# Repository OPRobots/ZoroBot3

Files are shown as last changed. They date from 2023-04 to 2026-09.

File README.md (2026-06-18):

# ZoroBot3

Tercera versión de nuestro primer robot. Un robot micromouse de alto rendimiento con STM32F4, encoders magneticos de alta resolución, succión y muchos leds molones.

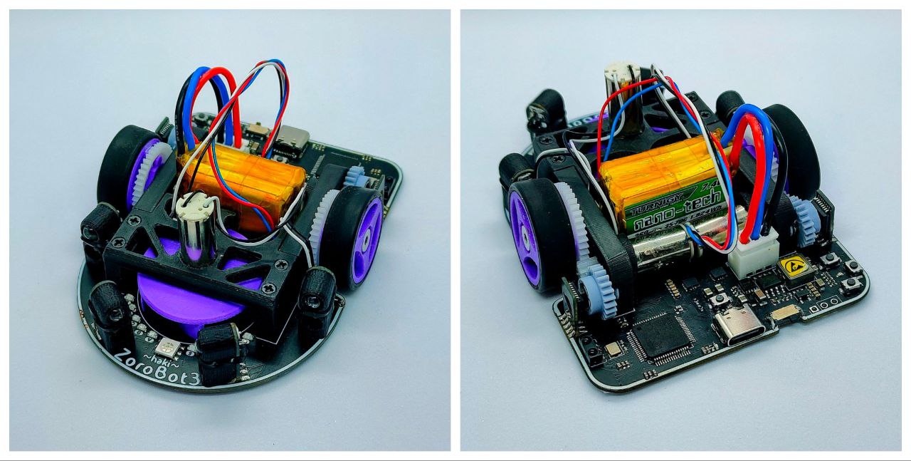
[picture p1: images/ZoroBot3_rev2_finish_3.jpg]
ZoroBot3


## 🏆 Palmarés

| 🥇 | 🥈 | 🥉 |
|:--:|:--:|:--:|
| **8** | **0** | **0** |

### Resultados por Evento

| Evento | Categoría | Posición | Año |
|---|---|:---:|:---:|
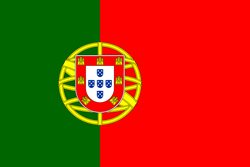
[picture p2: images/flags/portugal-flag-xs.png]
🇵🇹 Portugal
|  **Micromouse Portuguese Contest** | Micromouse Classic | 🥇 | 2026 |
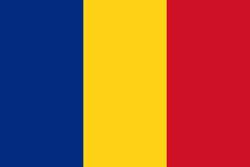
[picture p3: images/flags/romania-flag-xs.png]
🇷🇴 Rumanía
|  **RoboChallenge** | Maze | 🥇 | 2025 |
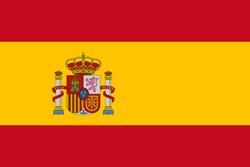
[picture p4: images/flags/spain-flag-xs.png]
🇪🇸 España
|  **OSHWDem** | Micromouse Classic | 🥇 | 2025 |
| 🇵🇹 Portugal **Micromouse Portugese Contest** | Micromouse Classic | 🥇 | 2025 |
| 🇵🇹 Portugal **Micromouse Portugese Contest** | Time Trial | 🥇 | 2025 |
| 🇷🇴 Rumanía **RoboChallenge** | Maze | 🥇 | 2024 |
| 🇪🇸 España **OSHWDem** | Micromouse Classic | 🥇 | 2024 |
| 🇪🇸 España **OSHWDem** | Micromouse Wall-Follower | 🥇 | 2023 |

---

## ⚙️ Hardware

- **Microcontrolador**: STM32F405RGT6 @168MHz
- **Driver de motores**: MP6551 @20kHz
- **Giroscopio**: LSM6DSRTR 4000dps
- **Encoders**: AS5145B-HSST
- **Mosfets**: AO3400 (A09T) Tanto para conmutar los emisores de los sensores como para la succión
- **Regulador**: CN3903 + LDO ME611C33M5G
- **Receptor IR 38kHz**: TSSP77038TR
- **Bateria**: LiPo 2S 260mAh 35-70C Turnigy nano-tech
- **Sensores**:
  - 4 Emisores IR SFH-4550
  - 4 Receptores IR ST-1KL3A
- **Tracción**:
  - 2x Motores Coreless 8520 7.4v genéricos (AliExpress)
  - Goma de ruedas Kyosho K.MZW39-30
  - Chasis de PCB con soportes de motores y ventilador en PLA
  - Piñones de motores 8T 0.5M
  - Engranajes de las ruedas 40T 0.5M
  - Engranajes de los encoders 22T 0.5M impresos en resina
  - 4x Rodamientos MR63ZZ (Ruedas)
  - 2x Rodamientos MR52ZZ (Encoders)
  - 2x Imán radial 6x2.5mm

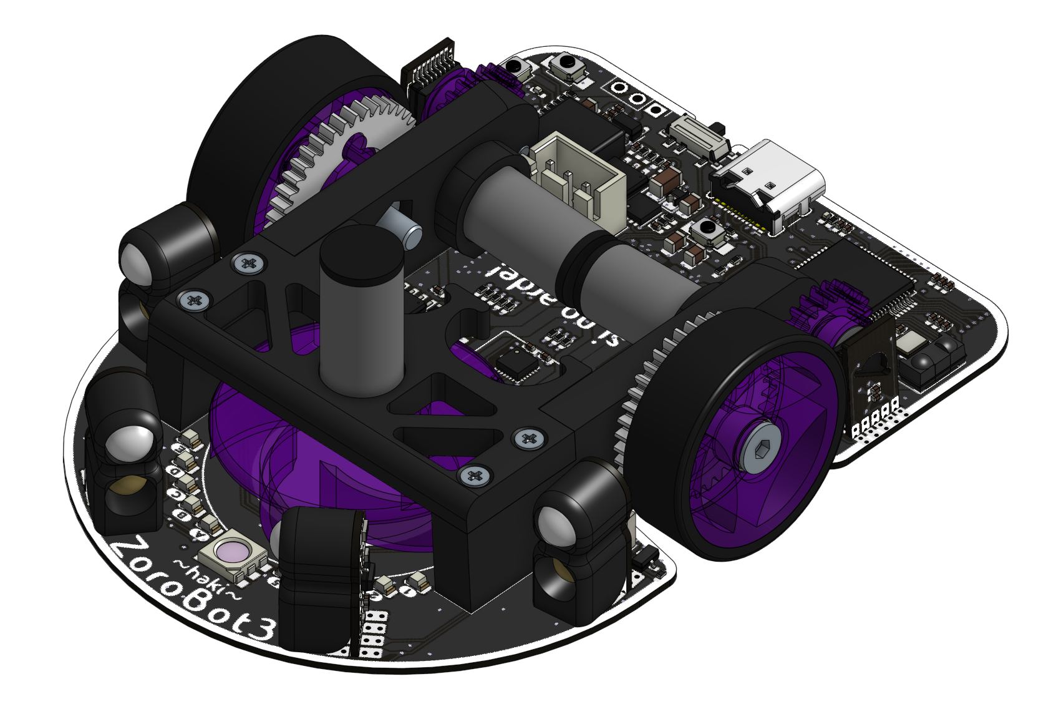
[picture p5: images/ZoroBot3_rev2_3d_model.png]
ZoroBot3 Chasis ZoroBot3 - Chasis


## 💻 Software

- Programado en VSCode y PlatformIO con LibOpenCM3.
- Todos los valores analógicos se leen mediante **DMA** y son procesados cada 1ms.
- Los sensores se leen mediante una máquina de estados a 16kHz, enciendiendo y apagando los emisores para **filtrar la luz ambiente**.
- El valor de los encoders se lee en **cuadratura por hardware** mediante dos timers.
- El MPU se lee mediante SPI.
- El bucle principal de control, del que constan los PID de velocidad lineal, velocidad angular, control frontal y control lateral se ejecuta cada 1ms.
- Se realiza un reseteo de posición por périda de pared lateral para mejorar la navegación.
- Las curvas se realizan mediante perfiles de giro con **aceleración senoidal** para mayor suavidad.
- Dispone de programas para seguimiento de pared derecha/izquierda, exploración y resolución mediante floodfill basado en pesos (más información en [TimeBased FloodFill Simulator](https://github.com/OPRobots/TimeBased-FloodFill-Simulator)) y hardcodeo de movimientos.

## 🎥 Vídeos

### Micromouse Portugese Contest 2026 - 🥇
<p align="center" width="100%">
<video src="https://github.com/user-attachments/assets/5a7cf803-e31e-463a-afa9-e5784b378937" width="80%" controls></video>
</p>

### OSHWDem 2025 - 🥇
<p align="center" width="100%">
<video src="https://github.com/user-attachments/assets/332fd117-6600-4692-b59f-4b1154166f3f" width="80%" controls></video>
</p>

### Micromouse Portugese Contest 2025 - 🥇
<p align="center" width="100%">
<video src="https://github.com/user-attachments/assets/cf21e942-3fe0-4065-8892-fa3d181a9791" width="80%" controls></video>
</p>

### RoboChallenge 2024 - 🥇
<p align="center" width="100%">
<video src="https://github.com/user-attachments/assets/a8c53e97-a756-4934-9c83-6c93fda1b235" width="80%" controls></video>
</p>

### OSHWDem 2024 - 🥇
<p align="center" width="100%">
<video src="https://github.com/user-attachments/assets/a70629e6-34b6-473f-afb0-14d8290bd128" width="80%" controls></video>
</p>

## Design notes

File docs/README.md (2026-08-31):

# Documentación Técnica de ZoroBot3

> Robot Micromouse de alto rendimiento con STM32F4, encoders magnéticos de alta resolución, ventilador de succión y 4 sensores infrarrojos.
>
> **Versión del documento**: 2026-08-25
> **Branch**: `develop`

---

## 🏆 Resultados en Competición

| 🥇 | 🥈 | 🥉 |
|:--:|:--:|:--:|
| **8** | **0** | **0** |

Competiciones ganadas: OSHWDem 2023-2025, RoboChallenge 2024-2025, Portuguese Contest 2025-2026.

---

## 📚 Índice de Documentación

Cada sección enlaza a un documento detallado independiente.

### 1. Hardware
- **[Hardware](01-hardware.md)** — Especificaciones del robot: MCU, sensores, motores, encoders, giroscopio, batería, chasis, PCB, versiones del robot (A/B/C).

### 2. Arquitectura Software
- **[Arquitectura Software](02-software-architecture.md)** — Bucle principal, SysTick ISR, distribución de tareas a 1 kHz, flujo de carrera, detección de inicio de competición, algoritmos de exploración.

### 3. Sensores
- **[Sistema de Sensores](03-sensors.md)** — Hardware IR (SFH-4550 + ST-1KL3A), máquina de estados ADC, linealización a distancia, detección de paredes con histéresis, calibración, cálculo de errores para control PID.

### 4. Movimiento
- **[Sistema de Movimiento](04-movement.md)** — Tipos de movimiento (26), perfiles de giro sinusoidales, movimientos rectos multi-celda, orquestración de speed run, wall loss correction.

### 5. Floodfill
- **[Algoritmo Floodfill](05-floodfill.md)** — Tipos (BASIC, DIAGONAL, TIME_BASED), cálculo de pesos cinemáticos, BFS con cola de prioridad, path following, exploración, speed run.

### 6. Control PID
- **[Sistema de Control PID](06-control-system.md)** — Arquitectura de 7 lazos PID en cascada, fórmula PID, anti-windup, compensación de batería, rampas de aceleración, detección de saturación.

### 7. Menú y Algoritmos de Ejecución
- **[Sistema de Menú](07-menu-system.md)** — Navegación por menú con botón, selección de algoritmo de exploración (HandWall, FloodFill, TimeTrial, DragRace), configuración de velocidad, opciones de debug.

### 8. Debug
- **[Sistema de Debug](08-debug-system.md)** — LEDs de información, LED RGB, puerto serie USART, funciones de debug, toma de valores raw.

### 9. Calibración
- **[Calibraciones](09-calibration.md)** — Calibración frontal, frontal media, lateral, calibración de giroscopio, persistencia en EEPROM.

### 10. Scripts: Calibración de Sensores IR
- **[Scripts de Calibración de Sensores](10-scripts-sensors.md)** — Herramienta offline (Jupyter) para calibrar los sensores IR: generación de perfiles de linealización, magics y structs C para el firmware.

### 11. EEPROM
- **[Gestión de EEPROM](11-eeprom.md)** — Diseño de almacenamiento, checksum (complemento a 2), carga/guardado de calibraciones, maze persistente, ocupación.

### 12. Encoders y Giroscopio
- **[Encoders y Giroscopio](12-encoders-gyro.md)** — AS5145B-HSST (12-bit), lectura por timer en cuadratura, max_likelihood_counter_diff, LSM6DSR (SPI, 1000-4000dps), filtro paso-bajo, integración angular.

### 13. Batería y LEDs
- **[Batería y LEDs](13-battery-leds.md)** — Monitorización de voltaje, divisor de tensión, LEDs de estado, LED RGB, control de ventilador.

### 14. Simulador
- **[Simulador MMSIM](14-simulator.md)** — Integración con Micromouse Simulator, API de paredes virtuales, estimación de tiempo.

### 15. Cinemática y Estrategias de Velocidad
- **[Cinemática](15-kinematics.md)** — Estrategias de velocidad (EXPLORE a HAKI), perfiles de aceleración, parámetros de giro, degradación de velocidad.

### 16. Scripts: Perfiles de Giro
- **[Scripts de Perfiles de Giro](16-scripts-turn-profiles.md)** — Sistema offline (Jupyter) de generación de perfiles de giro con aceleración angular sinusoidal, parámetros de entrada/salida por tipo de giro.

### 17. Problemas Conocidos
- **[Registro de Issues](17-known-issues.md)** — 64 issues documentados (10 críticos, 24 moderados, 30 leves) con IDs, descripciones, impacto y soluciones.

---

## 🔧 Stack Tecnológico

| Componente | Detalle |
|---|---|
| **MCU** | STM32F405RGT6 @ 168 MHz (ARM Cortex-M4F) |
| **Framework** | LibOpenCM3 + PlatformIO |
| **Lenguaje** | C11 |
| **Compilador** | GCC ARM Embedded (arm-none-eabi-gcc) |
| **IDE** | VSCode |
| **Control de versiones** | Git (branch `develop`) |

---

## 📐 Dimensiones del Laberinto

| Parámetro | Valor |
|---|---|
| Dimensión de celda | 180 mm |
| Diagonal de celda | 127.3 mm |
| Ancho de pared | 12 mm |
| Distancia centro a pared | 84 mm |
| Tamaño máximo | 16×16 celdas |
| Tamaño actual | 6×6 celdas |

---

## 🏗️ Estructura del Proyecto

```text
ZoroBot3/
├── docs/                    # 📚 Documentación (este directorio)
├── source_code/
│   ├── include/             # Headers (.h)
│   │   ├── config.h         # Configuración general, flags de compilación
│   │   ├── constants.h      # Constantes físicas y del sistema
│   │   ├── sensors.h        # API de sensores IR
│   │   ├── move.h           # API de movimiento + cinemática
│   │   ├── floodfill.h      # API de navegación
│   │   ├── control.h        # API de control PID
│   │   ├── menu.h           # API de menú
│   │   ├── calibrations.h   # API de calibración
│   │   ├── eeprom.h         # API de EEPROM
│   │   ├── encoders.h       # API de encoders
│   │   ├── lsm6dsr.h        # API de giroscopio
│   │   ├── leds.h           # API de LEDs
│   │   ├── battery.h        # API de batería
│   │   ├── motors.h         # API de motores
│   │   ├── utils.h          # Tabla de logaritmos
│   │   ├── handwall.h       # Algoritmo wall-follower
│   │   ├── timetrial.h      # Algoritmo time trial
│   │   ├── dragrace.h       # Algoritmo drag race
│   │   ├── debug.h          # Funciones de debug
│   │   ├── buttons.h        # Lectura de botones
│   │   ├── usart.h          # Puerto serie
│   │   ├── setup.h          # Inicialización hardware
│   │   ├── clock.h          # Timer del sistema
│   │   └── delay.h          # Delays
│   └── src/                 # Implementaciones (.c)
│       └── (archivos correspondientes a los headers)
├── pcb_files/               # Diseño PCB (KiCad)
├── scripts/                 # Scripts de calibración y análisis (Jupyter)
├── images/                  # Imágenes del robot
└── README.md                # README principal del proyecto
```

---

## ⚡ Frecuencias del Sistema

| Componente | Frecuencia | Detalle |
|---|---|---|
| SYSCLK | 168 MHz | System clock |
| SysTick ISR | 16 kHz | Interrupción base |
| sm_emitter_adc() | 16 kHz | Máquina de estados ADC |
| clock_tick() | 1 kHz | Timer del sistema |
| update_sensors_magics() | 1 kHz | Procesamiento de sensores |
| update_encoder_readings() | 1 kHz | Lectura de encoders |
| lsm6dsr_update() | 1 kHz | Lectura de giroscopio |
| control_loop() | 1 kHz | Bucle de control PID |
| update_battery_voltage() | 1 kHz | Lectura de batería |
| check_buttons() | 1 kHz | Lectura de botones |
| check_leds_while() | 1 kHz | Actualización de LEDs |
| PWM motores | 20 kHz | Frecuencia de conmutación |

---

## 🔄 Flujo de Alto Nivel

```mermaid
flowchart TD
    A["Inicio (main)"]
    A --> B["setup()<br>Inicialización hardware"]
    B --> C["eeprom_load()<br>Cargar calibraciones"]
    C --> D["handle_robot_version()<br>Detectar versión A/B/C"]
    D --> E["Bucle principal"]
    E --> F{"¿Carrera iniciada?"}
    F -->|"NO"| G["menu_handler()"]
    G --> G1["Seleccionar algoritmo"]
    G1 --> G2["Configurar parámetros"]
    G2 --> G3["Esperar inicio<br>(sensores frontales)"]
    F -->|"SÍ"| H{"Según algoritmo"}
    H -->|"EXPLORE_HANDWALL"| I["handwall_loop()"]
    H -->|"EXPLORE_FLOODFILL"| J["floodfill_loop()"]
    H -->|"EXPLORE_TIME_TRIAL"| K["timetrial_loop()"]
    H -->|"EXPLORE_DRAGRACE"| L["(inicia directamente)"]
    subgraph ISR["ISR SysTick (16 kHz, en paralelo)"]
        direction TB
        ISR1["sm_emitter_adc() — 16 kHz"]
        ISR2["Tareas a 1 kHz (módulo 16):<br>clock_tick() → check_leds_while() →<br>check_buttons() → update_battery_voltage() →<br>update_encoder_readings() →<br>update_sensors_magics() →<br>lsm6dsr_update() → control_loop()"]
        ISR1 --> ISR2
    end
```

---

## 📝 Notas sobre este Documento

- Las referencias a código fuente usan rutas relativas desde la raíz del proyecto (ej: [`source_code/src/sensors.c`](../source_code/src/sensors.c)).
- Los IDs de issues (FF-XX, SS-XX, MV-XX, HW-XX, SW-XX, SP-XX) se corresponden con el [registro de problemas conocidos](17-known-issues.md).

---

*Documento generado el 2026-08-25 para la versión `develop` del proyecto ZoroBot3.*

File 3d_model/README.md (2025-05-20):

# ZoroBot3
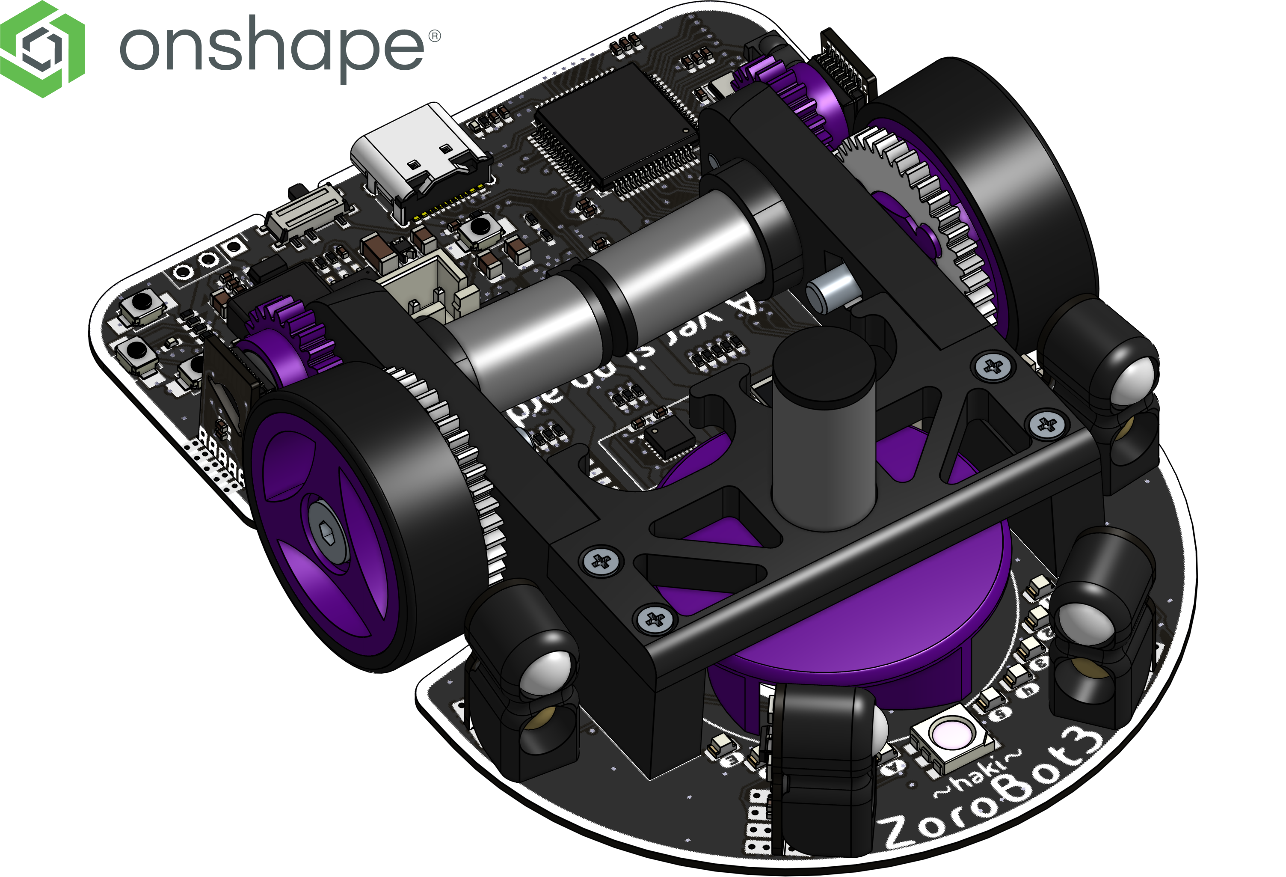
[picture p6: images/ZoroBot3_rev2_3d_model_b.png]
ZoroBot3 (https://cad.onshape.com/documents/c2349433f4c043eb0ce1efdc/w/394e4193cf2128d0e3f2c628/e/d0ea661264a18ad6b8f6ed22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)

El diseño de ZoroBot3 se encuentra disponible en [Onshape](https://cad.onshape.com/documents/c2349433f4c043eb0ce1efdc/w/394e4193cf2128d0e3f2c628/e/d0ea661264a18ad6b8f6ed22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), donde están diseñados todos los componentes del robot, incluyendo el chasis, la PCB y los engranajes.

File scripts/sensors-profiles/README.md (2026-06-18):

# Sensors Profiles — Calibración y Linealización de Sensores IR

## Índice

1. [Resumen](#resumen)
2. [Modelo matemático](#modelo-matemático)
3. [Estructura del notebook](#estructura-del-notebook)
4. [Flujo de trabajo](#flujo-de-trabajo)
5. [Uso en el firmware](#uso-en-el-firmware)
6. [Guía de uso](#guía-de-uso)
7. [Datasets de calibración](#datasets-de-calibración)
8. [Referencias](#referencias)

---

## Resumen

Este notebook de Jupyter (`sensors-profiles.ipynb`) calcula las constantes de calibración `(a, b, c)` que permiten convertir la lectura raw del ADC de los sensores IR del micromouse en distancia real en milímetros, mediante un modelo logarítmico empírico.

La salida del notebook son las constantes que se copian directamente en el firmware (`source_code/src/sensors.c`, función `set_sensors_robot_calibration()`), donde se usan en tiempo real para el control del robot.

---

## Modelo matemático

### Ecuación

```
distance (m) = a / ln(raw + c) - b
```

Donde:
- `raw` = valor del ADC (0–4095, lectura diferencial: sensor ON − sensor OFF)
- `a` = factor de escala (controla la forma de la curva logarítmica)
- `b` = offset (desplaza la curva verticalmente)
- `c` = offset del raw (desplaza horizontalmente, compensa el offset del sensor)

### Conversión a milímetros en el firmware

```c
// sensors.c:505-509
int16_t ln_index = (raw_filtered + calib.c) / 4;   // división entera
float ln = get_ln_value(ln_index);                  // lookup table: devuelve ln(ln_index * 4)
int16_t distance_mm = (int16_t)((calib.a / ln - calib.b) * 1000.0f);
```

El firmware usa una **lookup table de 1024 entradas** (`LOG_LINEARIZATION_TABLE_SIZE = 4096/4`) que almacena `ln(index * 4)`. La división entera por 4 introduce un error de cuantificación típicamente < 0.5% en distancia. El notebook incluye la función `raw_to_distance_firmware()` que simula esta cuantificación y reporta el error introducido (celda 6).

### Justificación física

Los sensores IR de reflectancia siguen aproximadamente la ley de la inversa del cuadrado: la intensidad reflejada es proporcional a `1/d²`. Esto implica que `raw ∝ 1/d²`, o equivalentemente `d ∝ 1/√raw`. El modelo `a/ln(raw+c) - b` es una aproximación empírica con asíntotas similares pero mejor comportamiento en los extremos del rango.

---

## Estructura del notebook

| Celda | Título | Contenido |
|---|---|---|
| 0 | _Imports_ | `numpy`, `pandas`, `matplotlib.pyplot`, `matplotlib.ticker`, `scipy.optimize.curve_fit` |
| 1 | Datos de calibración | `DATASETS` (lista de `{label, front_left, front_right, side_left, side_right}`), `ACTIVE_DATASETS`, `PLOT_MODE`. Invierte arrays y construye los DataFrames en `dfs`. |
| 2 | Visión general | Grid 2×2 con los valores raw de todos los robots activos superpuestos (`plt.cm.tab10`). |
| 3 | Funciones de modelo y utilidades | `raw_to_distance()`, `raw_to_distance_firmware()`, `estimate_p0()`, `compute_metrics()` |
| 4 | Selección de rangos | Define `RANGE_FRONT_*` y `RANGE_SIDE_*`. Crea DataFrames filtrados en `range_dfs`. Imprime tabla de raw mínimos por robot. |
| 5 | Ajuste de la curva | Define `fit_sensor()` y ajusta los 4 sensores × N datasets activos. Imprime parámetros ± incertidumbre + R²/RMSE. Almacena resultados en `results`. |
| 6 | Análisis de error | Calcula distancias ajustadas y errores para todos los datasets. Imprime `.describe()`, RMSE separado por rangos ajustados/excluidos, y error de cuantificación de la LUT. |
| 7 | Gráficas de error y curvas ajustadas | Genera 2 juegos de gráficas (error + curvas ajustadas), cada uno respetando `PLOT_MODE` (`"by_sensor"` o `"by_robot"`). |
| 8 | Structs C para el firmware | Imprime todos los structs C agrupados por robot con banner destacado, listos para copiar a `sensors.c`. |

---

## Flujo de trabajo

### 1. Obtención de datos

Se toman lecturas raw del ADC para cada sensor a distancias conocidas (0–250 mm, en pasos de 10 mm). Las lecturas se almacenan como arrays de 26 valores en `DATASETS` (celda 1), donde el primer valor corresponde a 250 mm (lejos) y el último a 0 mm (cerca). La inversión al orden ascendente se aplica automáticamente.

### 2. Filtrado por rangos de interés

El ajuste de curvas NO se hace sobre todos los datos. Se definen rangos prioritarios donde se necesita más precisión:

| Sensor | Rangos de ajuste | Rango excluido |
|---|---|---|
| Frontales | 20–70 mm y 100–150 mm | 70–100 mm |
| Laterales | 5–90 mm y 100–170 mm | 90–100 mm |

Los rangos excluidos corresponden a distancias de transición donde la precisión es menos crítica para la navegación en el laberinto. La celda 6 reporta el RMSE por separado para los rangos ajustados y los excluidos, permitiendo validar que la exclusión no degrada la precisión.

### 3. Ajuste de curvas

Se usa `scipy.optimize.curve_fit` con el método de mínimos cuadrados no lineales (Levenberg-Marquardt). Cada sensor se ajusta de forma independiente mediante `fit_sensor()` (celda 5), que encapsula todo el proceso:

1. `estimate_p0(raw_vals, dist_vals)` — estima `p0=[a, b, c=0]` resolviendo el modelo a partir de los extremos del rango de datos. `c=0` evita el colapso del logaritmo con valores raw bajos.
2. `curve_fit(...)` — ajusta los parámetros con bounds adecuados para cada tipo de sensor.
3. `np.sqrt(np.diag(pcov))` — calcula la incertidumbre de cada parámetro.
4. `compute_metrics(...)` — calcula R² y RMSE sobre los datos de ajuste.

- **Frontales**: `p0` automático, bounds `([-10, -1, -200], [10, 1, 200])`
- **Laterales**: `p0` automático, bounds `([-5, -2, -300], [5, 2, 300])`

### 4. Validación

La celda 6 realiza la validación completa sobre el dataset entero (no solo los rangos de ajuste):

- **Estadísticas descriptivas** (`.describe()`) del error de cada sensor
- **RMSE separado** por rangos ajustados vs excluidos, con conteo de muestras
- **Error de cuantificación de la LUT**: `raw_to_distance_firmware()` simula la división entera del firmware y se compara con el modelo float de precisión. Se reporta el error máximo y RMSE. Si el error máx > 3 mm, el notebook recomienda reajustar con el modelo firmware.

La celda 7 genera las gráficas de error y curvas ajustadas, respetando la variable `PLOT_MODE`:
- `"by_sensor"` — grid 2×2 con todos los robots superpuestos por colores
- `"by_robot"` — un figure por robot con sus 4 sensores

---

## Uso en el firmware

### Dónde se copian las constantes

Archivo: [`source_code/src/sensors.c`](../../source_code/src/sensors.c)

Función: `set_sensors_robot_calibration(uint16_t version)` (línea 67)

Las constantes se almacenan por versión de robot (`ZOROBOT3_A`, `ZOROBOT3_B`, `ZOROBOT3_C`, etc.). La celda 8 del notebook imprime los structs C listos para copiar, agrupados por robot con su etiqueta identificativa.

### Estructura de datos

```c
struct sensors_distance_calibration {
    float a;
    float b;
    float c;
};
```

### Procesamiento en tiempo real

En `update_sensors_magics()` (línea 486), cada ciclo:
1. Se calcula `raw_filtered` (mediana de 3 lecturas)
2. Se obtiene `ln_index = (raw_filtered + c) / 4`
3. Se busca `ln = get_ln_value(ln_index)` en la LUT
4. Se calcula `distance_mm = (a / ln - b) * 1000`
5. Se añaden offsets: distancia frontal del robot (`ROBOT_FRONT_LENGTH`) o ancho medio (`ROBOT_MIDDLE_WIDTH`)
6. Se aplica un filtro paso bajo (LPF) con α adaptativo (0.2 normal, 0.6 para cambios grandes)
7. Se aplica el offset de calibración guardado en EEPROM (`sensors_distance_offset`)

---

## Guía de uso

### Requisitos

```bash
pip install numpy pandas matplotlib scipy
```

En Arch Linux:
```bash
paru -S python-ipykernel python-numpy python-pandas python-matplotlib python-scipy
```

### Procedimiento para calibrar un nuevo robot

1. **Tomar medidas**: Colocar el robot frente a una pared a distancias conocidas (0–250 mm, pasos de 10 mm) y registrar el valor raw de cada sensor.

2. **Añadir datos al notebook**:
   - Añadir una nueva entry al array `DATASETS` en la celda 1 con el `label` del robot y sus 4 arrays de valores raw (orden: lejos → cerca)
   - Usar `ACTIVE_DATASETS` para seleccionar qué robots procesar (por defecto todos)

3. **Ajustar rangos si es necesario**: Modificar `RANGE_FRONT_*` y `RANGE_SIDE_*` en la celda 4 según las distancias críticas para este robot.

4. **Revisar `p0`**: La función `estimate_p0()` calcula automáticamente buenos valores iniciales. La celda 5 imprime los `p0` estimados para verificar que son razonables.

5. **Ejecutar todas las celdas**: `Cell > Run All`

6. **Verificar errores**:
   - RMSE < 5 mm en rangos ajustados → calibración aceptable
   - RMSE > 10 mm en rangos ajustados → revisar datos o modelo
   - Si algún `a` sale negativo → los datos no siguen el modelo logarítmico, revisar mediciones
   - Error de cuantificación LUT (celda 6) > 3 mm → considerar reajustar con `raw_to_distance_firmware()`

7. **Copiar constantes al firmware**:
   - Copiar la salida de la **celda 8** (structs C agrupados al final)
   - Pegar en `set_sensors_robot_calibration()` en `sensors.c`
   - Añadir un nuevo `case ZOROBOT3_X:` con las constantes

### Solución de problemas

| Síntoma | Causa probable | Solución |
|---|---|---|
| `a` negativo en el ajuste | Datos no siguen el modelo logarítmico | Revisar mediciones, verificar que `raw` decrece con la distancia |
| Error grande en rangos excluidos | La curva no extrapola bien a esos rangos | Ampliar los rangos de ajuste en la celda 4 |
| RMSE > 10 mm en todos los sensores | Datos de calibración ruidosos o mal tomados | Repetir las mediciones, verificar iluminación |
| La LUT del firmware da resultados distintos | Error de cuantificación por división entera | Revisar el error reportado en la celda 6; si > 3 mm, usar `raw_to_distance_firmware()` en `curve_fit` |

---

## Referencias

- Firmware: [`source_code/src/sensors.c`](../../source_code/src/sensors.c) — `set_sensors_robot_calibration()`, `update_sensors_magics()`
- LUT de logaritmo: [`source_code/src/utils.c`](../../source_code/src/utils.c) — `ln_lookup[]`, `get_ln_value()`
- Constantes: [`source_code/include/constants.h`](../../source_code/include/constants.h) — `ADC_RESOLUTION`, `LOG_LINEARIZATION_TABLE_STEP`
- Estructura de calibración: [`source_code/include/sensors.h`](../../source_code/include/sensors.h) — `struct sensors_distance_calibration`

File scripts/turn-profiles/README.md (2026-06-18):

# Micromouse Sinusoidal Turn Profiles

Generador de perfiles de giro con aceleración angular sinusoidal para un robot micromouse de alto rendimiento (ZoroBot3).

## Índice

- [Descripción general](#descripción-general)
- [Arquitectura](#arquitectura)
- [Sistema de coordenadas](#sistema-de-coordenadas)
- [Flujo de generación de un perfil](#flujo-de-generación-de-un-perfil)
- [Estructuras de datos clave](#estructuras-de-datos-clave)
- [Convención de signos de `.start` y `.end`](#convención-de-signos-de-start-y-end)
- [Uso del notebook](#uso-del-notebook)
- [Estrategias de velocidad](#estrategias-de-velocidad)
- [Tipos de giro](#tipos-de-giro)
- [Parámetros de salida](#parámetros-de-salida)
- [Problemas conocidos](#problemas-conocidos)
- [Archivos](#archivos)

---

## Descripción general

Este sistema genera perfiles de trayectoria para giros slalom alrededor de postes en un laberinto de micromouse. El perfil usa **aceleración angular sinusoidal** para producir transiciones suaves (jerk limitado), lo que minimiza el deslizamiento de las ruedas y el estrés mecánico.

Cada perfil describe:
- La trayectoria `(x, y)` del centro del robot
- Las trayectorias de los bordes izquierdo y derecho del robot
- El margen de seguridad respecto al poste
- Las fuerzas centrífuga y de aceleración angular
- Las distancias de entrada/salida necesarias para encadenar giros

## Arquitectura

```
micromouse_sinusoidal_turn_profiles_aux.py
│
├── Maze               — dimensiones de la celda y poste
├── RobotPhysics       — masa, inercia, geometría del robot
├── Line               — recta definida por punto de referencia y ángulo
├── lines_intersection — intersección de dos rectas
├── TurnProfile        — perfil de giro básico (in-place)
├── SlalomTurnProfile  — perfil de giro slalom con entrada/salida
├── turn_profile()     — genera perfil de velocidad angular sinusoidal
├── complete_profile() — integra velocidades → posiciones y fuerzas
├── complete_slalom_profile() — alinea con líneas de entrada/salida
├── turn_shift()       — calcula desplazamiento para alinear perfil
└── Simulator          — orquesta la generación de perfiles
```

### Clases principales

| Clase | Responsabilidad |
|---|---|
| `Maze` | Dimensiones físicas: `cell` (0.18m), `post` (0.012m) |
| `RobotPhysics` | Parámetros del robot: masa, inercia, ancho, separación de ruedas, velocidad angular máxima |
| `Line` | Modela una línea por su punto de referencia `(x, y)` y su `angle`. Calcula `slope` e `intercept`. |
| `Simulator` | Punto de entrada. Métodos: `inplace()` (giro sin desplazamiento) y `slalom()` (giro con trayectoria curva) |
| `SlalomTurnProfile` | Contiene el perfil generado más las líneas de entrada/salida. Métodos: `describe()`, `describe_profile()`, `plot_trajectory()`, `plot_forces()` |

## Sistema de coordenadas

Las coordenadas de entrada/salida se definen en **unidades de celda** relativas al poste:

```
                Norte
              (0, +0.5) 
                  |
Oeste (-0.5, 0) --+-- (+0.5, 0) Este
                  |
              (0, -0.5)
                 Sur
```

- `(0, 0)` = centro del poste
- `(0, -0.5)` = centro del borde de la celda sur
- `(+0.5, 0)` = centro del borde de la celda este
- Una unidad de celda = 0.18 m (se multiplica dentro de `Simulator.slalom()`)

Los ángulos siguen la convención matemática estándar:
- `0` = Este (+x)
- `π/2` = Norte (+y)
- `π` = Oeste (-x)
- `3π/2` = Sur (-y)

## Flujo de generación de un perfil

### 1. `Simulator.slalom(entry, exit, radius, linear_velocity, shift=None)`

1. Convierte coordenadas de celda a metros
2. Calcula el ángulo total del giro: `angle = exit.angle - entry.angle`
3. Calcula la fuerza centrífuga necesaria: `F = m·v² / (2·r)`
4. Calcula la velocidad angular máxima: `ω_max = v / r` (limitada por `robot.max_angular_velocity`)
5. Calcula la aceleración angular máxima: `α_max = F · d_ruedas / I`
6. Verifica que la transición sinusoidal pueda alcanzar `ω_max`
7. Genera el perfil con `turn_profile()`
8. Completa el perfil con `complete_profile()`
9. Alinea el perfil con `complete_slalom_profile()`

### 2. `turn_profile(angle, ω_max, α_max, dt)`

Genera un perfil de velocidad angular con tres fases:

```
         ω_max  ───────────────
               ╱                ╲
             ╱                    ╲
    0  ─────                      ─────
    |--transition--|--arc--|--transition--|
```

- **Transición de entrada**: sinusoidal, `ω(t) = ω_max · sin(t/transition · π/2)`
- **Arco constante**: `ω(t) = ω_max` (velocidad angular máxima)
- **Transición de salida**: sinusoidal decreciente

Parámetros calculados:
- `duration = ω_max / α_max · π`
- `transition_angle = duration · ω_max / π`
- `arc = (|angle| - 2·transition_angle) / ω_max` (duración del arco)
- `transition = duration / 2` (duración de cada transición)

### 3. `complete_profile(profile, entry_angle, radius, v, robot, dt)`

Integra las velocidades para obtener posiciones, ángulos y fuerzas:

- **Ángulo**: `angle[t] = Σ(ω[t]·dt) + entry_angle`
- **Posición X**: `x[t] = Σ(v·cos(angle[t])·dt)`
- **Posición Y**: `y[t] = Σ(v·sin(angle[t])·dt)`
- **Fuerza centrífuga**: `Fc = m·v·ω / 2`
- **Fuerza aceleración angular**: `Fα = |I·α / d_ruedas|`
- **Fuerza total**: `F = √(Fc² + Fα²)`

### 4. `complete_slalom_profile(profile, entry, exit, robot, maze, shift=None)`

1. **Calcula el desplazamiento** (`shift`):
   - Si `shift=None`: usa `turn_shift()` automáticamente
   - Si se proporciona `shift` manual: `shift_final = shift + entry.reference`
2. **Aplica el desplazamiento** a todas las coordenadas x,y
3. **Calcula los bordes del robot**: añade/substrae `robot.width/2` perpendicular a la trayectoria
4. **Calcula el margen al poste**: distancia mínima de los bordes al poste más cercano

### 5. `turn_shift(entry, exit, profile)`

```python
expected = lines_intersection(entry, exit)
start = Line(profile[0].x, profile[0].y, angle=entry.angle)
stop  = Line(profile[-1].x, profile[-1].y, angle=exit.angle)
actual = lines_intersection(start, stop)
return expected - actual
```

Alinea el "centro de giro" del perfil con el punto de intersección de las líneas de entrada y salida del laberinto.

**Limitación**: solo funciona cuando las líneas de entrada y salida NO son paralelas. Para giros de 180° (líneas paralelas), se requiere un `shift` manual.

## Convención de signos de `.start` y `.end`

Los valores `.start` y `.end` representan la distancia (en mm) desde el primer/último punto del perfil hasta el **sensing point** (línea divisora de casillas) de entrada/salida, **con signo**. El signo indica si el perfil *reduce* o *aumenta* el tramo recto anterior/posterior:

| Efecto sobre el tramo recto | `.start` | `.end` |
|---|---|---|
| **Negativo** → reduce el tramo recto anterior/posterior | El perfil empieza **antes** del sensing point (se acerca a él; el tramo recto previo se acorta) | El perfil termina **después** del sensing point (ya lo pasó; el tramo recto posterior se acorta) |
| **Positivo** → aumenta el tramo recto anterior/posterior | El perfil empieza **después** del sensing point (ya lo pasó; el tramo recto previo se alarga) | El perfil termina **antes** del sensing point (aún no llega; el tramo recto posterior se alarga) |

El punto de referencia es siempre la **línea divisoria** entre casillas (sensing point), no el centro del poste ni la línea central del pasillo.

- **`.start` negativo** (`-68.8 mm`): el perfil comienza 68.8 mm **antes** de cruzar la línea divisoria de entrada → el tramo recto de aproximación se **reduce** en 68.8 mm porque el robot empieza a girar antes de llegar a ella.
- **`.start` positivo** (`+47.9 mm`): el perfil comienza 47.9 mm **después** de cruzar la línea divisoria de entrada → el tramo recto de aproximación se **alarga** en 47.9 mm porque el robot ya ha entrado en la celda cuando empieza a girar.
- **`.end` negativo** (`-68.8 mm`): el perfil termina 68.8 mm **después** de cruzar la línea divisoria de salida → el tramo recto posterior se **reduce** en 68.8 mm porque el robot ya ha salido de la celda cuando termina el giro.
- **`.end` positivo** (`+47.9 mm`): el perfil termina 47.9 mm **antes** de cruzar la línea divisoria de salida → el tramo recto posterior se **alarga** en 47.9 mm porque el robot termina el giro antes de llegar a ella.

> **Regla mnemotécnica**: negativo = el perfil se *come* parte del tramo recto (lo reduce); positivo = el perfil *deja espacio* antes/después del sensing point (lo aumenta).

El signo se determina comparando la distancia del primer punto del perfil con la del punto siguiente (para `.start`), o la del último punto con la del punto anterior (para `.end`). Si la distancia al sensing point disminuye → el robot se acerca a él (signo negativo para `.start`, positivo para `.end`); si aumenta → se aleja (signo positivo para `.start`, negativo para `.end`).

## Uso del notebook

### Requisitos

```python
pip install ipykernel numpy pandas matplotlib
```

En caso de usar Arch Linux, instalar los paquetes del sistema:
```python
paru -S python-ipykernel python-numpy python-pandas python-matplotlib
```

### Ejecución

Abrir `turn-profiles.ipynb` en Jupyter y ejecutar todas las celdas en orden:

1. **Setup** (celda 2): define el laberinto, robot y simulador
2. **Definición de perfiles** (celda 5): genera todos los perfiles para cada velocidad
3. **Visualización** (celdas 8-18): muestra trayectorias y genera estructuras C

### Personalización

Para añadir una nueva velocidad o modificar parámetros:

```python
# En la celda 5, añadir:
nueva_velocidad90 = simulate.slalom(
    entry=(0, -.5, 0),      # Entrada: sur, rumbo este
    exit=(.5, 0, pi/2),      # Salida: este, rumbo norte
    radius=0.135,            # Radio de giro (m)
    linear_velocity=2.0      # Velocidad lineal (m/s)
)
```

### Robot físico

Parámetros actuales del robot:

| Parámetro | Valor | Descripción |
|---|---|---|
| Masa | 0.070 kg | Masa total del robot |
| Momento de inercia | 8.75×10⁻⁵ kg·m² | I = m·r²/2 (disco) |
| Ancho | 0.0702 m | Ancho total |
| Separación ruedas | 0.062 m | Distancia entre ruedas |
| ω_max | 40 rad/s | Velocidad angular máxima |

## Estrategias de velocidad

Cada estrategia define velocidades lineales crecientes para el mismo conjunto de giros:

| Estrategia | v_90 (m/s) | v_180 (m/s) | v_45 (m/s) | v_135 (m/s) | v_45to45 (m/s) |
|---|---|---|---|---|---|
| EXPLORE | 0.800 | — | — | — | — |
| NORMAL | 1.696 | 1.350 | 1.644 | 1.118 | 0.955 |
| MEDIUM | 1.932 | 1.575 | 1.865 | 1.305 | 1.114 |
| FAST | 2.220 | 1.800 | 2.146 | 1.491 | 1.273 |
| SUPER | 2.490 | 2.025 | 2.404 | 1.678 | 1.432 |
| HAKI | 2.745 | 2.250 | 2.647 | 1.864 | 1.591 |

Las velocidades más altas producen fuerzas laterales mayores; el radio de giro y la velocidad deben equilibrarse para no superar los límites de fricción.

## Tipos de giro

### Giros principales

| Tipo | Ángulo | Entry | Exit | Radio (m) | Notas |
|---|---|---|---|---|---|
| **MOVE_90** | 90° | `(0, -.5, 0)` | `(.5, 0, π/2)` | 0.135 | Giro estándar en L |
| **MOVE_180** | 180° | `(0, -.5, 0)` | `(0, .5, π)` | 0.090 | Giro en U. **Usa shift manual** |
| **MOVE_TO_45** | 45° | `(0, -.5, 0)` | `(.5, 0, π/4)` | 0.120 | Giro de 45° |
| **MOVE_TO_135** | 135° | `(0, -.5, 0)` | `(0, .5, 3π/4)` | 0.07456 | Giro de 135° |
| **MOVE_45_TO_45** | 90° | `(0, -.5, π/4)` | `(0, .5, 3π/4)` | 0.06364 | Giro diagonal-diagonal |
| **MOVE_FROM_45** | 45° | `(0, -.5, π/4)` | `(.5, 0, π/2)` | 0.120 | Complementario de TO_45 |
| **MOVE_FROM_45_180** | 135° | `(0, -.5, π/4)` | `(0, .5, π)` | 0.07456 | Complementario de TO_135 |

### Líneas de entrada y salida

Cada giro se define sobre dos líneas del laberinto (los ejes centrales de los pasillos). Todas las entradas están al **sur** del poste; las salidas al **este** o al **norte**:

| Línea | Ecuación | Dirección | Tipo | Usada por |
|---|---|---|---|---|
| **E-H** (Entry Horizontal) | `y = -90 mm` | Este (0°) | Entrada | MOVE_90, MOVE_180, MOVE_TO_45, MOVE_TO_135 |
| **E-D** (Entry Diagonal) | `y = x - 90 mm` | Noreste (45°) | Entrada | MOVE_45_TO_45, MOVE_FROM_45, MOVE_FROM_45_180 |
| **X-V** (Exit Vertical) | `x = 90 mm` | Norte (90°) | Salida | MOVE_90, MOVE_FROM_45 |
| **X-H** (Exit Horizontal) | `y = 90 mm` | Oeste (180°) | Salida | MOVE_180, MOVE_FROM_45_180 |
| **X-D** (Exit Diagonal NE) | `y = x - 90 mm` | Noreste (45°) | Salida | MOVE_TO_45 |
| **X-Dnw** (Exit Diagonal NW) | `y = -x + 90 mm` | Noroeste (135°) | Salida | MOVE_TO_135, MOVE_45_TO_45 |

> **Nota**: X-D (salida de MOVE_TO_45) es exactamente la misma línea que E-D (entrada de los giros diagonales). Esta es la **única** coincidencia entre una línea de salida y una de entrada.

### Encadenamiento de giros

Para encadenar dos giros A→B, la línea de salida de A debe conectar geométricamente con la línea de entrada de B. Se distinguen dos casos:

#### Caso 1: Línea compartida (misma recta)

La salida de A y la entrada de B están en **la misma línea** geométrica. Solo ocurre con X-D = E-D (`y = x - 90 mm`):

| Giro A | Giro B | Gap físico | Segmento recto necesario |
|---|---|---|---|
| MOVE_TO_45 | MOVE_45_TO_45 | 34.1 mm | 34.1 mm recto diagonal |
| MOVE_TO_45 | MOVE_FROM_45 | 18.9 mm | 18.9 mm recto diagonal |
| MOVE_TO_45 | MOVE_FROM_45_180 | 25.1 mm | 25.1 mm recto diagonal |

En los tres casos, los puntos de referencia de salida de A `(90, 0) mm` y de entrada de B `(0, -90) mm` están separados por `CELL_HALF_DIAGONAL = 127.28 mm` sobre la misma diagonal. Los offsets `.end` y `.start` posicionan los puntos físicos del perfil a lo largo de esta línea, dejando gaps pequeños (19-34 mm) que deben recorrerse en recto.

#### Caso 2: Líneas diferentes — se requiere trayectoria intermedia

Para todos los demás 39 pares, la línea de salida y la de entrada son **diferentes**. La conexión requiere navegar por la geometría del laberinto. Se han identificado 7 combinaciones distintas de líneas:

| # | Salida de A | Entrada de B | Relación | Distancia entre refs | Conexión necesaria |
|---|---|---|---|---|---|
| 1 | X-Dnw (`y=-x+90`) | E-H (`y=-90`) | ⊥ (45°) | 127.28 mm | Recta diagonal CELL_HALF_DIAGONAL (127.28 mm) |
| 2 | X-Dnw (`y=-x+90`) | E-D (`y=x-90`) | ⊥ (90°) | 127.28 mm | Giro de 90° en el poste + recta |
| 3 | X-H (`y=90`) | E-H (`y=-90`) | ∥ (paralelas) | 180.00 mm | 1 CELL recto vertical |
| 4 | X-H (`y=90`) | E-D (`y=x-90`) | ⊥ (45°) | 180.00 mm | Navegación por celda |
| 5 | X-D (`y=x-90`) | E-H (`y=-90`) | ⊥ (45°) | 127.28 mm | Recta diagonal CELL_HALF_DIAGONAL |
| 6 | X-V (`x=90`) | E-H (`y=-90`) | ⊥ (90°) | 127.28 mm | Giro de 90° en el poste |
| 7 | X-V (`x=90`) | E-D (`y=x-90`) | ⊥ (45°) | 127.28 mm | Recta diagonal CELL_HALF_DIAGONAL |

Donde:
- **⊥ (45°)**: líneas a 45° (una horizontal/vertical y una diagonal) — requieren CELL_HALF_DIAGONAL
- **⊥ (90°)**: líneas perpendiculares (horizontal y vertical) — el poste está en la intersección
- **∥**: líneas paralelas — requieren CELL de separación

**El caso TO_135 → FROM_45_180**: la salida de TO_135 es por X-Dnw (`y = -x + 90mm`, ref en `(0, 90mm)`) y la entrada de FROM_45_180 es por E-D (`y = x - 90mm`, ref en `(0, -90mm)`). Son líneas diagonales perpendiculares que se cruzan en el poste. Con los puntos de referencia corregidos (ver [Problema #2](#2-move_to_135--move_from_45_180-referencia-de-salida-incorrecta)), `.end` y `.start` coinciden (+47.97 mm para NORMAL), por lo que los offsets ya codifican correctamente los tramos rectos de entrada/salida sin requerir un gap intermedio adicional.

**El caso FROM_45_180 → TO_135** (inverso): la salida de FROM_45_180 es por X-H (`y = 90mm`) y la entrada de TO_135 es por E-H (`y = -90mm`). Son líneas paralelas separadas 180 mm (1 CELL). Con los valores corregidos, `.start = -26.59 mm` y `.end = -26.59 mm` también coinciden entre ambos giros, completando la simetría inversa del par.

### Tabla resumen de offsets para el firmware

Valores de `.start` y `.end` para todas las velocidades (NORMAL, en mm):

| Giro | `.start` | `.end` | Notas |
|---|---|---|---|
| MOVE_90 | -68.83 | -68.83 | Simétrico. Ambos negativos → reducen los tramos rectos de entrada y salida |
| MOVE_180 | -44.99 | -45.06 | Simétrico. Ambos negativos → reducen los tramos rectos de entrada y salida. **Requiere shift manual** |
| MOVE_TO_45 | -73.07 | +54.21 | Reduce tramo recto de entrada, alarga el de salida |
| MOVE_TO_135 | -26.59 | +47.97 | Reduce tramo recto de entrada, alarga el de salida |
| MOVE_45_TO_45 | +39.02 | +39.01 | Simétrico. Ambos positivos → alargan los tramos rectos de entrada y salida |
| MOVE_FROM_45 | +54.21 | -73.07 | Alarga tramo recto de entrada, reduce el de salida. Inverso de TO_45 |
| MOVE_FROM_45_180 | +47.97 | -26.59 | Alarga tramo recto de entrada, reduce el de salida. Inverso de TO_135 |

## Parámetros de salida

Cada perfil genera una estructura C con estos campos:

```c
struct turn_params {
    float start;              // Distancia de entrada (mm, con signo)
    float end;                // Distancia de salida (mm, con signo)
    uint16_t linear_speed;    // Velocidad lineal (mm/s)
    float max_angular_speed;  // Velocidad angular máxima (rad/s)
    float transition;         // Duración de transición (ms)
    float arc;                // Duración del arco (ms)
    int8_t sign;              // +1 = giro derecha, -1 = giro izquierda
};
```

Ejemplo de salida para NORMAL_LEFT_90:
```c
[MOVE_LEFT_90] = {
    .start = -68.8257,         // 68.8 mm antes de la referencia de entrada
    .end = -68.8336,           // 68.8 mm después de la referencia de salida
    .linear_speed = 1696,      // 1.696 m/s
    .max_angular_speed = 12.5630,
    .transition = 63.3541,     // 63.4 ms por transición
    .arc = 131.4061,           // 131.4 ms de arco constante
    .sign = -1,                // giro a izquierda
},
```

## Problemas conocidos

### 1. MOVE_180: Asimetría en `.start` / `.end`

**Estado**: ✅ CORREGIDO (2026-06-13)

**Descripción**: Para giros de 180°, el `exit` original era `(.5, 0, π)` (línea de salida horizontal `y=0` pasando por el centro del poste). Con radio 0.09m, el perfil tiene un desplazamiento vertical natural de ~182 mm pero la distancia entre las líneas de entrada (`y=-90mm`) y salida (`y=0mm`) era solo 90 mm — un desajuste geométrico de 2× que causaba `.start` ≠ `.end` (ratio 3.64×) y un error de 92.5 mm en la línea de salida.

**Solución aplicada**: Cambiar el `exit` de `(.5, 0, π)` → `(0, .5, π)` (salida al norte, línea `y=0.09`, heading oeste). La distancia vertical entre líneas pasa a ser 0.18 m, acercándose al desplazamiento natural del perfil (~0.1825 m).

**Resultados tras la corrección**:

| Velocidad | \|start\| | \|end\| | Ratio | Error salida |
|---|---|---|---|---|
| NORMAL | 44.99 mm | 45.06 mm | 1.002× | 2.55 mm |
| MEDIUM | 44.98 mm | 45.06 mm | 1.002× | 2.55 mm |
| FAST | 44.98 mm | 45.07 mm | 1.002× | 2.55 mm |
| SUPER | 44.98 mm | 45.06 mm | 1.002× | 2.55 mm |
| HAKI | 44.98 mm | 45.07 mm | 1.002× | 2.55 mm |

**Nota**: El error residual de ~2.55 mm en la línea de salida se debe a que el desplazamiento vertical del perfil (182.55 mm) no es exactamente 180 mm. Ajustar el componente `y` del shift manual a `-0.00127` en vez de `0` eliminaría este error repartiéndolo simétricamente (1.27 mm en cada extremo). No obstante, 2.55 mm es aceptable para la aplicación.

### 2. MOVE_TO_135 / MOVE_FROM_45_180: Referencia de salida incorrecta

**Estado**: ✅ CORREGIDO (2026-06-15)

**Descripción**: El notebook generaba `TO_135.end = -79.31 mm` porque usaba `exit=(.5, 0, 3π/4)` — referencia de salida en (90mm, 0). El valor correcto debe ser `+47.97 mm` para que coincida con `FROM_45_180.start`, como exige el firmware (comentario en `move.c:111`: *"El .end tiene que ser el .start y el .start tiene que ser el .end del MOVE_****_FROM_45_180"*).

**Causa raíz**: La línea de salida de TO_135 es `y = -x + 90mm`. Tanto (90, 0) como (0, 90) están sobre esta misma línea, pero el `.end` mide la distancia desde el punto de referencia, no desde la línea. Con la referencia incorrecta en (90, 0), el perfil termina en (33.92, 56.08) y la distancia es 79.31mm (signo negativo porque ya pasó la referencia). Con la referencia corregida en (0, 90), la distancia al mismo punto físico es 47.97mm (signo positivo porque aún no llega a la referencia).

**Solución aplicada**: Cambiar `exit=(.5, 0, 3π/4)` → `exit=(0, .5, 3π/4)` en las 5 velocidades del notebook. Esto NO cambia la trayectoria física (misma línea, mismo `turn_shift()`, mismas posiciones) — solo cambia desde qué punto de la línea se mide `.end`.

**Resultados tras la corrección**:

| Velocidad | TO_135.end | FROM_45_180.start | ¿Coinciden? |
|---|---|---|---|
| NORMAL | +47.97 mm | +47.97 mm | ✅ |
| MEDIUM | +47.97 mm | +47.97 mm | ✅ |
| FAST | +47.97 mm | +47.97 mm | ✅ |
| SUPER | +47.97 mm | +47.97 mm | ✅ |
| HAKI | +47.97 mm | +47.97 mm | ✅ |

**Interpretación geométrica correcta**:

```
        (0, 90mm) ← TO_135.exit_ref CORREGIDO
        ×
        |\
        | \        TO_135: el robot recorre 47.97mm recto
        |  \       desde el fin del arco hasta el límite de celda
        |   \
        |    \     FROM_45_180: el robot empieza 47.97mm después
        ×-----×    de la referencia de entrada, ya dentro de la celda
  (0,0)       (0, -90mm)
  poste       FROM_45_180.entry_ref
```

- **TO_135**: entra por el sur (heading E), gira 135° alrededor del poste, y el arco termina en (33.92, 56.08) mm. Desde ahí, el robot recorre **47.97 mm recto en dirección NW** hasta alcanzar el límite de la celda en (0, 90) mm.
- **FROM_45_180**: el robot entra en la celda por (0, -90) mm heading NE, y ya ha avanzado **47.97 mm** dentro de la celda cuando empieza el arco del giro (en (33.92, -56.08) mm).
- `.start = -26.59 mm` y `.end = -26.59 mm` también coinciden entre TO_135 y FROM_45_180 respectivamente, completando la simetría inversa del par.

**Por qué el análisis anterior era incorrecto**: La diferencia de 127.28 mm (CELL_HALF_DIAGONAL) entre `|-79.31|` y `|+47.97|` era un artefacto de usar el punto de referencia equivocado. No existe ningún "gap" que requiera un movimiento recto diagonal intermedio — los valores `.start`/`.end` ya codifican correctamente los tramos rectos de aproximación y salida cuando se usa la referencia adecuada.

### 3. Dependencia de shift manual para 180°

**Estado**: ⚠️ Limitación de diseño (funcional con la geometría corregida)

El `shift` manual `(-0.045, 0)` para giros de 180° sigue siendo necesario porque `turn_shift()` no funciona con líneas paralelas (entry angle=0, exit angle=π → slope=0 ambas). Con la geometría corregida (`exit=(0, .5, π)`), el shift actual produce resultados casi simétricos (ratio ~1.002, error <3mm). Un ajuste fino del componente `y` del shift a `-0.00127` daría simetría perfecta, pero no es necesario para la aplicación práctica.

### 4. Limitación de `turn_shift()` con líneas paralelas

`lines_intersection()` lanza `ValueError` cuando las pendientes son iguales. Esto afecta a cualquier configuración donde las líneas de entrada y salida sean paralelas (ángulos que difieren en múltiplos de π).

## Archivos

### `micromouse_sinusoidal_turn_profiles_aux.py` — Biblioteca principal

Motor de cálculo de perfiles de giro sinusoidal para micromouse. Contiene todas las clases y funciones necesarias para generar, alinear, analizar y visualizar trayectorias de giro.

**Clases:**

| Clase | Descripción |
|---|---|
| `Maze` | Parámetros del laberinto: `cell` (0.18m), `post` (0.012m) |
| `RobotPhysics` | Parámetros físicos: masa, momento de inercia, ancho, separación de ruedas, velocidad angular máxima |
| `Line` | Línea recta infinita definida por punto de referencia `(x, y)` y `angle`. Calcula `slope` e `intercept` |
| `TurnProfile` | Clase base con DataFrame `profile` y método `plot_forces()` |
| `SlalomTurnProfile(TurnProfile)` | Perfil completo con referencias `entry`/`exit`. Métodos: `describe()`, `describe_profile()`, `plot_trajectory()`, `plot_forces()` |
| `Simulator` | Orquestador. Métodos: `inplace()` para giros en el sitio, `slalom()` para giros con desplazamiento |

**Funciones principales:**

| Función | Descripción |
|---|---|
| `lines_intersection(l0, l1)` | Calcula el punto de intersección de dos líneas. Lanza `ValueError` si son paralelas |
| `turn_shift(entry, exit, profile)` | Calcula el vector de desplazamiento para alinear la trayectoria generada con las líneas de entrada/salida deseadas. Compara la intersección esperada con la real |
| `turn_profile(angle, max_av, max_aa, period)` | Genera perfil de velocidad angular sinusoidal: aceleración (seno 0→π/2), constante, deceleración (seno π/2→0) |
| `complete_profile(profile, start_angle, radius, lv, robot, period)` | Integra cinemáticamente: ángulo, posición (x,y), fuerzas (centrífuga, aceleración angular, total) |
| `complete_slalom_profile(profile, entry, exit, maze, robot, shift)` | Aplica `turn_shift()`, desplaza la trayectoria, calcula trayectorias de bordes del robot, margen al poste |

---

### `turn-profiles.ipynb` — Notebook principal

Define, genera y visualiza los 7 perfiles de giro para cada una de las 5 estrategias de velocidad (EXPLORE, NORMAL, MEDIUM, FAST, SUPER, HAKI). Para cada velocidad imprime los structs C listos para copiar al firmware.

**Estructura del notebook:**

| Celda | Contenido |
|---|---|
| 0-4 | Setup: imports, constantes del robot, simulador |
| 5 | Definición de los 7 perfiles × 6 velocidades |
| 6-18 | Salida de structs C + gráficas de trayectoria para cada velocidad |

**Perfiles definidos (todos los movimientos MOVE_LEFT_* y MOVE_RIGHT_*):**

| Variable | Movimiento | entry | exit | Ángulo | Radio |
|---|---|---|---|---|---|
| `*90` | 90° estándar | `(0, -.5, 0)` | `(.5, 0, π/2)` | 90° | 0.135m |
| `*180` | 180° | `(0, -.5, 0)` | `(0, .5, π)` | 180° | 0.09m |
| `*45` / `*To45` | TO_45 | `(0, -.5, 0)` | `(.5, 0, π/4)` | 45° | 0.12m |
| `*135` / `*To135` | TO_135 | `(0, -.5, 0)` | `(0, .5, 3π/4)` | 135° | 0.07456m |
| `*45to45` | 45_TO_45 | `(0, -.5, π/4)` | `(0, .5, 3π/4)` | 90° | 0.06364m |
| `*From45` | FROM_45 | `(0, -.5, π/4)` | `(.5, 0, π/2)` | 45° | 0.12m |
| `*From45to180` | FROM_45_180 | `(0, -.5, π/4)` | `(0, .5, π)` | 135° | 0.07456m |

**Coordenadas de celda:** Los valores `.5` y `-.5` se escalan por `maze.cell` (0.18m):
- `(0, -.5)` → `(0, -90mm)` — centro del pasillo sur
- `(.5, 0)` → `(90mm, 0)` — centro del pasillo este
- `(0, .5)` → `(0, 90mm)` — centro del pasillo norte
- `(0, .5)` → `(0, 90mm)` — centro del pasillo norte

---

### `verify_profiles.py` — Verificación de casos problemáticos

Script que comprueba sistemáticamente las relaciones esperadas entre pares de perfiles de giro para las 5 velocidades.

**Casos verificados:**

| Caso | Verificación | Criterio |
|---|---|---|
| **CASE 1** — MOVE_180 | `|.start| ≈ |.end|` | Simetría del giro de 180° |
| **CASE 2** — TO_135 ↔ FROM_45_180 | `.start₁ ≈ .end₂` y `.end₁ ≈ .start₂` | Correspondencia de par inverso |
| **CASE 3** — TO_45 ↔ FROM_45 | `.start₁ ≈ -.end₂` y `.end₁ ≈ -.start₂` | Par simétrico de referencia |

**Análisis adicional:**
- Geometría de líneas de entrada/salida para cada caso
- Verificación de que los puntos inicial/final están sobre sus respectivas líneas (error en mm)
- Relación entre la línea de salida de TO_135 y la de entrada de FROM_45_180
- Análisis de por qué los giros de 180° requieren `shift` manual (líneas paralelas)

**Uso:**
```bash
python3 verify_profiles.py
```

---

### `deep_analysis.py` — Trazado paso a paso de la generación de perfiles

Script que desglosa el proceso interno de generación de perfiles para entender exactamente cómo se calculan los desplazamientos, las distancias y los signos.

**Partes del análisis:**

| Parte | Contenido |
|---|---|
| **PART 1** — 180° deep trace | Por qué el perfil de 180° es asimétrico: el desplazamiento vertical natural del perfil (~0.1825m) es ~2× el requerido (0.09m con el exit antiguo) |
| **PART 2** — TO_135 vs FROM_45_180 | Comparación de ángulos de giro (ambos 135°), shifts aplicados, posiciones físicas de los endpoints, diferencia con el par TO_45/FROM_45 que sí comparte línea |
| **PART 3** — Sign convention | Análisis detallado de cómo se determinan los signos de `.start` y `.end`: compara `norm(p[1]-ref)` con `norm(p[0]-ref)` para determinar si el robot se aproxima o se aleja |

**Uso:**
```bash
python3 deep_analysis.py
```

---

### `analyze_all_pairs.py` — Análisis exhaustivo de encadenamiento de giros

Script que analiza todas las combinaciones posibles de pares de giros (7×7 = 49 pares) para determinar cuáles pueden encadenarse directamente y qué segmento recto intermedio necesita cada par.

**Partes del análisis:**

| Parte | Contenido |
|---|---|
| **PART 1** — Entry/Exit lines | Lista todas las líneas de entrada y salida de cada tipo de giro, mostrando ecuación, referencia y ángulo |
| **PART 2** — Direct chains | Identifica pares donde la línea de salida de A coincide exactamente con la línea de entrada de B (misma pendiente e intercepto) |
| **PART 3** — Direct chain analysis | Para cada par encadenable, calcula offsets, gaps físicos, y verifica la consistencia geométrica |
| **PART 4** — Non-direct pairs | Para pares no encadenables, analiza el ángulo entre líneas (paralelas, perpendiculares, 90°), punto de intersección, y distancias |
| **PART 5** — Reference distance matrix | Matriz 7×7 de distancias entre referencia de salida de A y referencia de entrada de B (mm) |
| **PART 6** — Straight segment analysis | Para pares encadenables, calcula la distancia recta necesaria entre el fin físico de A y el inicio físico de B |

**Uso:**
```bash
python3 analyze_all_pairs.py
```

---

### `test_new_exit.py` — Prueba de corrección de geometría para MOVE_180

Script que evalúa el cambio de `exit` para giros de 180°: de `(.5, 0, π)` (línea horizontal y=0 que pasa por el centro del poste) a `(0, .5, π)` (línea horizontal y=0.09 al norte del poste).

**Partes del análisis:**

| Parte | Contenido |
|---|---|
| **PART 1** — OLD vs NEW | Compara `.start`/`.end` y simetría para las 5 velocidades con ambas definiciones de exit |
| **PART 2** — Optimal shift | Calcula el shift óptimo para la nueva geometría minimizando el error en ambas líneas |
| **PART 3** — Shift strategies | Prueba 4 estrategias: shift actual, shift óptimo, shift en Y solamente, sin shift |
| **PART 4** — Safety check | Verifica que el margen al poste se mantiene seguro para todas las velocidades |
| **PART 5** — Summary | Resumen de la mejora geométrica: con el nuevo exit, la distancia vertical entre líneas (0.18m) se aproxima mucho más al desplazamiento natural del perfil (~0.1825m) |

**Uso:**
```bash
python3 test_new_exit.py
```

---

### Flujo de trabajo típico

```
1. Definir/ajustar perfiles en turn-profiles.ipynb
2. Ejecutar el notebook para generar structs C y gráficas
3. Verificar con verify_profiles.py que los pares cumplen las relaciones esperadas
4. Si hay discrepancias, depurar con deep_analysis.py
5. Para análisis global de encadenamiento, usar analyze_all_pairs.py
6. Copiar los structs generados al firmware (move.c)
```

### Dependencias

- Python ≥ 3.10
- NumPy, Pandas, Matplotlib
- Jupyter (para el notebook)

Los scripts `.py` son independientes y no requieren Jupyter — solo importan la biblioteca auxiliar.

---

## Referencias

- **Robot**: ZoroBot3 — micromouse de competición
- **Laberinto**: Micromouse clásico (celda 0.18m, poste 0.012m)
- **Modelo físico**: Aceleración angular sinusoidal para minimizar jerk
- **Formato de salida**: Estructuras C para el firmware del robot

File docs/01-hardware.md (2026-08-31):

# Hardware

## Microcontrolador

| Característica | Detalle |
|---|---|
| **Modelo** | STM32F405RGT6 |
| **Arquitectura** | ARM Cortex-M4F (FPU) |
| **Frecuencia** | 168 MHz |
| **Flash** | 1 MB |
| **RAM** | 192 KB |
| **Framework** | LibOpenCM3 |
| **Entorno** | PlatformIO + VSCode |

El STM32F405RGT6 proporciona:
- **Timers**: TIM3 y TIM4 para lectura de encoders en modo contador. TIM2 y TIM5 generan PWM para motores (20 kHz).
- **ADC**: ADC2 para lectura de 4 sensores IR + 4 canales auxiliares (batería, corriente motores, botón menú).
- **SPI**: SPI3 compartido entre el giroscopio LSM6DSR (CS PA15), el MPU-6500 de placa (U1, CS PA15) y la SRAM externa 23AA04M (CS PB12).
- **USART**: USART3 para printf por puerto serie (115200 baud).
- **DMA**: Usado para lecturas ADC.
- **GPIO**: Control de emisores IR, LEDs, habilitación de motores, chip select SPI.

---

## Sensores Infrarrojos

### Componentes

| Componente | Modelo | Cantidad |
|---|---|---|
| **Emisor IR** | SFH-4550 (GaAs, 860 nm, alta eficiencia) | 4 |
| **Receptor IR** | ST-1KL3A (fototransistor, encapsulado negro) | 4 |

### Disposición

| Sensor | ID | Canal ADC | GPIO Emitter | Función |
|---|----|---|---|---|
| Front Left | `SENSOR_FRONT_LEFT_WALL_ID` (0) | ADC_CHANNEL10 (PC0) | PA0 | Pared frontal izquierda |
| Front Right | `SENSOR_FRONT_RIGHT_WALL_ID` (1) | ADC_CHANNEL13 (PC3) | PA3 | Pared frontal derecha |
| Side Left | `SENSOR_SIDE_LEFT_WALL_ID` (2) | ADC_CHANNEL12 (PC2) | PA2 | Pared lateral izquierda |
| Side Right | `SENSOR_SIDE_RIGHT_WALL_ID` (3) | ADC_CHANNEL11 (PC1) | PA1 | Pared lateral derecha |

### Principio de Funcionamiento

1. **Medición diferencial**: Se mide `sensors_off` (LED apagado, luz ambiental) y `sensors_on` (LED encendido). La señal útil = `on - off`.
2. **Ley física**: La relación entre distancia y lectura sigue aproximadamente `reading ≈ k / distance²`.
3. **Secuencia**: Solo se enciende un LED a la vez para evitar crosstalk óptico.

---

## Encoders Magnéticos

| Característica | Detalle |
|---|---|
| **Modelo** | AS5145B-HSST |
| **Resolución** | 12 bits (4096 posiciones/revolución) |
| **Interfaz** | Timer en modo contador (cuadratura por hardware) |
| **Timer izquierda** | TIM4 |
| **Timer derecha** | TIM3 |
| **Micrómetros por tick** | 10.494055 μm |

Conversión: `μm = ticks × 10.494055`. Derivado de `(π × diámetro_rueda) / 4096`.

**Relación de engranajes**:
- Piñón motor: 8T 0.5M
- Engranaje rueda: 40T 0.5M
- Engranaje encoder: 22T 0.5M (resina)

---

## Giroscopio

| Característica | Detalle |
|---|---|
| **Modelo** | LSM6DSRTR |
| **Interfaz** | SPI3 (PA15 = CS) |
| **Rangos** | 1000 / 2000 / 4000 dps |
| **ODR** | 1666 Hz |
| **Filtro** | Paso-bajo LIGHT (~100 Hz en 1000 dps) |
| **Block Data Update** | Habilitado |

El full-scale se cambia dinámicamente según la estrategia de velocidad (1000 dps en exploración, 2000 dps en carrera).

---

## SRAM Externa

| Característica | Detalle |
|---|---|
| **Modelo** | 23AA04M-I/ST (Microchip, TSSOP-8) |
| **Capacidad** | 4 Mbit (512 KiB) |
| **Interfaz** | SPI3 (bus compartido con el giroscopio) |
| **CS** | PB12 (net `NSS_SRAM`, pull-up 10 kΩ) |
| **Componentes auxiliares** | RRAM1 (10 kΩ pull-up) y CSRAM1 (100 nF decoupling) |

> ⚠️ La SRAM está añadida en el esquemático pero aún no está colocada en la PCB ni
> tiene driver en el firmware (ver [HW-01](17-known-issues.md#hw-01) y
> [HW-05](17-known-issues.md#hw-05)).

---

## Motores y Tracción

| Componente | Detalle |
|---|---|
| **Motores** | 2× Coreless 8520 7.4V (genéricos) |
| **Driver** | MP6551 @ 20 kHz PWM |
| **Ruedas** | Goma Kyosho K.MZW39-30 |
| **Rodamientos ruedas** | 4× MR63ZZ |
| **Rodamientos encoders** | 2× MR52ZZ |
| **Imán encoders** | 2× Radial 6×2.5mm |
| **Ventilador** | Succión controlada por MOSFET NMOS (Q1) con PWM |

### PWM y control
- Resolución PWM: 1024 niveles (10 bits)
- Frecuencia PWM motores: 20 kHz
- MOSFET AON7423 (Q2, canal P) en la entrada de batería; emisores IR conmutados por GPIO y ventilador por Q1 (NMOS)

---

## Alimentación

| Componente | Detalle |
|---|---|
| **Batería** | LiPo 2S 260mAh 35-70C Turnigy nano-tech |
| **Regulador principal** | CN3903 (buck DC-DC) |
| **LDO** | ME611C33M5G (3.3V para MCU y sensores) |
| **Rango 2S** | 7.4V (bajo) - 8.4V (alto) |
| **Soporte 3S** | 11.0V - 12.6V (requiere cambiar `VOLT_DIV_FACTOR`) |

---

## Chasis y PCB

- **Chasis**: PCB principal con soportes de motores y ventilador en PLA
- **Diseño PCB**: KiCad (archivos en `pcb_files/`)
- **Piezas impresas**: 11 archivos STL (soportes, engranajes, ruedas, ventilador)

---

## Versiones del Robot

Existen 3 versiones del robot identificadas por el STM32 UID (Unique ID):

| Versión | Enum | Identificación |
|---|---|---|
| ZOROBOT3_A | 1 | Primera revisión |
| ZOROBOT3_B | 2 | Segunda revisión |
| ZOROBOT3_C | 3 | Tercera revisión |

Cada versión tiene diferentes parámetros de calibración ABC para los sensores (ver [Sensores](03-sensors.md#parametros-abc-por-version-del-robot)).

La detección se realiza en `handle_robot_version()` leyendo `UID_WORD0` del registro `0x1FFF7A10`.

---

## Pinout y Periféricos

### ADC2 (Sensores + Auxiliares)
| Canal | GPIO | Función |
|---|---|---|
| CH10 | PC0 | Sensor Front Left |
| CH13 | PC3 | Sensor Front Right |
| CH12 | PC2 | Sensor Side Left |
| CH11 | PC1 | Sensor Side Right |
| CH4 | PA4 | Batería (AUX_BATTERY_ID) |
| CH14 | PC4 | Corriente motor izquierdo (sin amplificador front-end — ver [HW-02](17-known-issues.md#hw-02)) |
| CH15 | PC5 | Corriente motor derecho (sin amplificador front-end — ver [HW-02](17-known-issues.md#hw-02)) |
| CH8 | PB0 | Botón de menú (AUX_MENU_BTN_ID) |

### SPI3 (Giroscopio + SRAM)
| GPIO | Función |
|---|---|
| PA15 | CS giroscopio (LSM6DSR vía conector DATA_MPU1; MPU-6500 U1 comparte bus y CS) |
| PB12 | CS SRAM (NSS_SRAM, pull-up 10 kΩ) |
| PC10 | SCK |
| PC11 | MISO |
| PC12 | MOSI |

### USART3 (Debug)
| GPIO | Función |
|---|---|
| PC6 | TX |
| PC7 | RX |

### GPIO Control
| GPIO | Función |
|---|---|
| PA0-PA3 | Emisores IR (LED ON/OFF) |
| PB13 | LED de estado |
| PB14 | LED RGB (TIM12, CH1-3) |
| PA6-PA7, PC8-PC9, PB1-PB2, PA11-PA12, PB8-PB9 | LEDs de información (10) |
| PB6-PB7 | Botones de menú |
| PB15 | Driver motores enable |
| PB10 | Ventilador (PWM) |

### Receptor IR
| Componente | Detalle |
|---|---|
| **Modelo** | TSSP77038TR |
| **Frecuencia** | 38 kHz |
| **Protocolo** | RC5 |

---

## Esquema de Bloques

```mermaid
flowchart TB
    subgraph MCU["STM32F405RGT6 @ 168 MHz"]
        direction TB
        subgraph row1[" "]
            direction LR
            P1["TIM3/4<br>Encoders (L,R)"]
            P2["SPI3<br>LSM6DSR (Gyro)<br>+ SRAM 23AA04M"]
            P3["ADC2<br>4×IR + 4×Aux"]
        end
        subgraph row2[" "]
            direction LR
            P4["TIM2/5<br>PWM 20 kHz<br>(Motores)"]
            P5["USART3<br>Debug<br>115200"]
            P6["GPIO<br>IR LEDs<br>Info LEDs"]
        end
        DMA["DMA<br>Transferencias ADC automáticas"]
        P3 --> DMA
    end
```

---

*Documento generado el 2026-08-25. Referencia cruzada con [Sensores](03-sensors.md), [Encoders y Giroscopio](12-encoders-gyro.md), [Problemas Conocidos](17-known-issues.md).*

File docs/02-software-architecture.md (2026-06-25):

# Arquitectura Software

## Visión General

ZoroBot3 utiliza una arquitectura de **dos niveles**:

| Nivel | Contexto | Frecuencia | Responsabilidad |
|---|---|---|---|
| **ISR (SysTick)** | Interrupción | 16 kHz | Control en tiempo real |
| **Main Loop** | Bucle principal | Variable | Máquinas de estado de alto nivel |

El ISR ejecuta el control motor y lectura de sensores de forma determinista. El bucle principal ejecuta funciones bloqueantes de alto nivel (movimientos, navegación) mientras el ISR mantiene el control en segundo plano.

---

## SysTick ISR

Archivo: [`source_code/src/main.c:23-58`](../source_code/src/main.c#L23-L58)

```c
void sys_tick_handler(void) {
    static uint8_t tick_count = 0;

    sm_emitter_adc();  // 16 kHz — siempre

    switch (tick_count) {
        case 0: clock_tick(); break;              // 1 kHz
        case 1: check_leds_while(); break;        // 1 kHz
        case 2: check_buttons(); break;           // 1 kHz
        case 3: update_battery_voltage(); break;  // 1 kHz
        case 4: update_encoder_readings(); break; // 1 kHz
        case 5: update_sensors_magics(); break;   // 1 kHz
        case 6: lsm6dsr_update(); break;          // 1 kHz
        case 7: control_loop(); break;            // 1 kHz
    }

    tick_count = (tick_count + 1) % 16;
}
```

### Distribución Temporal

```mermaid
flowchart TD
    A["SysTick 16 kHz (62.5 µs por tick)"]
    A --> B["sm_emitter_adc()<br>CADA tick (16 kHz)"]
    A --> C["Contador módulo 16<br>(1 kHz por tarea)"]
    C --> D["[0] clock_tick()<br>Reloj del sistema"]
    C --> E["[1] check_leds_while()<br>Actualización LEDs"]
    C --> F["[2] check_buttons()<br>Lectura de botones"]
    C --> G["[3] update_battery_voltage()<br>Medición batería"]
    C --> H["[4] update_encoder_readings()<br>Lectura encoders"]
    C --> I["[5] update_sensors_magics()<br>Procesado sensores"]
    C --> J["[6] lsm6dsr_update()<br>Lectura giroscopio"]
    C --> K["[7] control_loop()<br>Control PID motores"]
```

> **Nota**: La frecuencia efectiva de 1 kHz por tarea depende de que SysTick sea exactamente 16 kHz. Si el prescaler no coincide, todas las frecuencias derivadas serán incorrectas. Ver [issue MV-18](17-known-issues.md#mv-18).

---

## Bucle Principal

Archivo: [`source_code/src/main.c:60-205`](../source_code/src/main.c#L60-L205)

```mermaid
flowchart TD
    A["main()"]
    A --> B["setup()<br>Inicialización de hardware"]
    B --> C["eeprom_load()<br>Cargar calibraciones guardadas"]
    C --> D["handle_robot_version()<br>Detectar versión del robot"]
    D --> E["show_battery_level()<br>Mostrar nivel de batería en LEDs"]
    E --> F["while(1)"]

    F --> G{"¿Carrera iniciada?<br>(is_race_started)"}

    G -->|"NO"| H["menu_handler()<br>Navegación por menú"]
    H --> I["Activar/desactivar sensores<br>Según estado del menú"]
    I --> J{"¿menu_run_can_start()?"}
    J -->|"Sí"| K["check_start_run()<br>Detectar mano en sensores"]
    K --> L{"¿Detectó inicio?<br>(is_race_started)"}
    L -->|"Sí"| M{"Según algoritmo<br>seleccionado"}
    M -->|"EXPLORE_HANDWALL"| N1["handwall_start()"]
    M -->|"EXPLORE_FLOODFILL"| N2["floodfill_start_explore()<br>o floodfill_start_run()"]
    M -->|"EXPLORE_TIME_TRIAL"| N3["timetrial_start()"]
    M -->|"EXPLORE_DRAGRACE"| N4["dragrace_start()"]

    G -->|"SÍ"| O{"Según algoritmo"}
    O -->|"EXPLORE_HANDWALL"| P1["handwall_loop()"]
    O -->|"EXPLORE_FLOODFILL"| P2["floodfill_loop()"]
    O -->|"EXPLORE_TIME_TRIAL"| P3["timetrial_loop()"]
```

### Modelo de Ejecución

El bucle principal llama a funciones **bloqueantes** para movimientos como `move_straight()`. Mientras estas funciones esperan (bucle `while` comprobando distancia recorrida), el **ISR SysTick** ejecuta el control PID en segundo plano, actualizando los PWM de los motores en tiempo real.

Esto crea un modelo de ejecución cooperativo donde:
- El **main loop** decide QUÉ hacer (high-level planning)
- El **ISR** decide CÓMO hacerlo (low-level control)

---

## Inicio de Competición

### `check_start_run()` ([`control.c:167-219`](../source_code/src/control.c#L167-L219))

El robot detecta automáticamente el inicio de competición mediante los sensores frontales:

1. Si cualquier sensor frontal detecta distancia ≤ `SENSOR_FRONT_DETECTION_START` (100 mm), se inicia un temporizador.
2. Si la detección persiste ≥ `SENSOR_START_MIN_MS` (350 ms), se arranca la carrera.
3. **Ventana de auto-run**: 2 segundos para que el segundo sensor detecte (modo auto-run). Si el sensor opuesto también detecta, se activa `race_auto_run`.

- **Sensor izquierdo (FL) activado** → El robot usa la mano izquierda o empieza floodfill en modo run.
- **Sensor derecho (FR) activado** → El robot usa la mano derecha o empieza floodfill en modo explore.

Para `EXPLORE_DRAGRACE`, no se usa `check_start_run()` — la carrera arranca directamente al pulsar start.

---

## Algoritmos de Exploración

Seleccionables desde el menú (ver [Menú](07-menu-system.md)):

### EXPLORE_HANDWALL (0)
- **Wall follower**: El robot sigue la pared con la mano izquierda o derecha.
- Detecta qué mano usar según el sensor frontal que se active primero.
- Simple y robusto para laberintos sin islas.
- Archivos: [`handwall.c`](../source_code/src/handwall.c), [`handwall.h`](../source_code/include/handwall.h)

### EXPLORE_FLOODFILL (2)
- **Navegación inteligente**: Usa el algoritmo floodfill para encontrar el camino óptimo.
- Explora celdas no visitadas, construye el mapa, y ejecuta speed run.
- Soporta 3 modos de exploración: `EXPLORE_SIMPLE`, `EXPLORE_HOME`, `EXPLORE_COMPLETE`.
- Archivos: [`floodfill.c`](../source_code/src/floodfill.c), [`floodfill.h`](../source_code/include/floodfill.h)

### EXPLORE_TIME_TRIAL (1)
- **Time trial**: Speed run en una pista predefinida (no maze).
- Ejecuta una secuencia de movimientos cronometrada.
- Archivos: [`timetrial.c`](../source_code/src/timetrial.c), [`timetrial.h`](../source_code/include/timetrial.h)

### EXPLORE_DRAGRACE (3)
- **Drag race**: Aceleración máxima en línea recta.
- Sin navegación — solo velocidad punta.
- Archivos: [`dragrace.c`](../source_code/src/dragrace.c), [`dragrace.h`](../source_code/include/dragrace.h)

---

## Modo Carrera (Speed Run)

Cuando el floodfill ha explorado el laberinto, se activa el modo carrera (`race_mode = true`):

1. `build_run_sequence()` — Genera la secuencia óptima de movimientos.
2. `smooth_run_sequence()` — Convierte la secuencia en movimientos físicos con optimización de diagonales.
3. `move_run_sequence()` — Ejecuta los movimientos a máxima velocidad con cinemática configurada.

La velocidad de carrera se configura desde el menú (SPEED_EXPLORE a SPEED_HAKI).

---

## Compilación Condicional

### `USE_RAW_SENSORS` ([`config.h:55`](../source_code/include/config.h#L55))

```c
#define USE_RAW_SENSORS true
```

Controla el modo de detección de paredes:
- **true**: Usa valores ADC raw (más estable, menos sensible a ruido de linealización)
- **false**: Usa distancia en mm (más intuitivo, unidades físicas)

### `MMSIM_ENABLED`

Cuando se compila para el simulador:
- Las lecturas de sensores se reemplazan por `API_wallFront()`, `API_wallLeft()`, `API_wallRight()`
- No hay hardware real (ADC, SPI, GPIO)
- Ver [Simulador](14-simulator.md)

### `CONFIG_RUN_RACE` / `CONFIG_RUN_DEBUG` ([`config.h:71-72`](../source_code/include/config.h#L71-L72))

Controla el modo de ejecución por defecto (RACE o DEBUG).

---

## Diagrama de Flujo General

```mermaid
flowchart TD
    subgraph ISR["SysTick ISR (16 kHz)"]
        direction TB
        ISR1["sm_emitter_adc() × 16 kHz<br>Máquina de estados: LED OFF → read → LED ON → read"]
        ISR2["Tareas a 1 kHz (módulo 16):<br>clock → LEDs → buttons → battery → encoders →<br>sensors_magics → gyro → control_loop"]
        ISR1 --> ISR2
    end

    ISR --> MAIN

    subgraph MAIN["Main Loop (variable)"]
        direction TB
        ML1["MENU"]
        ML2["check_start_run()"]
        ML3["ALGORITMO"]
        ML4["FIN"]
        ML1 --> ML2 --> ML3 --> ML4
        ML3 --> ML3a["handwall_loop()"]
        ML3 --> ML3b["floodfill_loop()"]
        ML3 --> ML3c["timetrial_loop()"]
        ML3b --> ML3b1["loop_explore()"]
        ML3b --> ML3b2["loop_run()"]
    end
```

---

*Documento generado el 2026-06-12. Referencias: [Control PID](06-control-system.md), [Menú](07-menu-system.md), [Floodfill](05-floodfill.md).*

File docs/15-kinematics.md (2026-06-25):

# Cinemática y Estrategias de Velocidad

## Estructuras de Datos

Archivo: [`move.h`](../source_code/include/move.h)

### `struct kinematics` — Configuración cinemática activa

```c
struct kinematics {
    int16_t linear_speed;                  // Velocidad lineal por defecto (mm/s)
    struct linear_accel_params linear_accel; // Aceleraciones
    int16_t fan_speed_2s;                  // Ventilador en 2S
    int16_t fan_speed_3s;                  // Ventilador en 3S
    struct turn_params *turns;             // Array de parámetros de giro
    struct kpi_params *kpi;                // Ganancias PID
    struct mpu_params mpu;                 // Config del giroscopio
};
```

### `struct turn_params` — Parámetros de un giro

```c
struct turn_params {
    float start;              // Distancia desde el sensing point de entrada (mm).
                              //   Negativo → el perfil empieza antes del sensing point
                              //              (reduce el tramo recto previo).
                              //   Positivo → el perfil empieza después del sensing point
                              //              (alarga el tramo recto previo).
    float end;                // Distancia desde el sensing point de salida (mm).
                              //   Negativo → el perfil termina después del sensing point
                              //              (reduce el tramo recto posterior).
                              //   Positivo → el perfil termina antes del sensing point
                              //              (alarga el tramo recto posterior).
    int16_t linear_speed;     // Velocidad lineal durante el giro (mm/s)
    float max_angular_speed;  // Velocidad angular máxima (rad/s)
    float transition;         // Duración de la transición sinusoidal (ms)
    float arc;                // Duración del arco a velocidad constante (ms)
    int8_t sign;              // −1 = izquierda, +1 = derecha
};
```

### `struct linear_accel_params` — Aceleraciones lineales

```c
struct linear_accel_params {
    int16_t break_accel;      // Deceleración (mm/s²)
    int16_t accel_hard;       // Aceleración inicial (mm/s²)
    int16_t speed_hard;       // Umbral para cambiar a accel_soft (mm/s)
    int16_t accel_soft;       // Aceleración reducida (mm/s²)
};
```

---

## Estrategias de Velocidad

6 niveles de `enum speed_strategy`:

| Estrategia | Velocidad (mm/s) | Break | accel_hard | speed_hard | accel_soft | Full-Scale Gyro |
|---|:---:|:---:|:---:|:---:|:---:|:---:|
| `SPEED_EXPLORE` | 800 (explore) / 3500 (run) | 8000 | 8000 | — | — | 1000 dps |
| `SPEED_NORMAL` | 3000 | 12000 | 12000 | — | — | 2000 dps |
| `SPEED_MEDIUM` | 5000 | 15000 | 15000 | — | — | 2000 dps |
| `SPEED_FAST` | 5500 | 20000 | 20000 | 3500 | 15000 | 2000 dps |
| `SPEED_SUPER` | 6000 | 25000 | 25000 | 4000 | 20000 | 2000 dps |
| `SPEED_HAKI` | 6500 | 30000 | 30000 | 4500 | 25000 | 2000 dps |

### Notas

- **SPEED_EXPLORE**: Velocidad dual — 800 mm/s en exploración (`configure_explore_kinematics(false)`), 3500 mm/s en run (`configure_explore_kinematics(true)`).
- **SPEED_NORMAL y MEDIUM**: Aceleración simple (sin `speed_hard`/`accel_soft`).
- **SPEED_FAST, SUPER, HAKI**: Aceleración en dos etapas para evitar deslizamiento de ruedas a altas velocidades.

### Cambio de Estrategia

```c
configure_kinematics(SPEED_FAST);
// → Copia la estrategia a 'kinematics'
// → Actualiza full-scale del giroscopio si cambió
// → Resetea acumuladores de error PID
```

---

## Parámetros de Giro

Cada estrategia tiene su propio array `turn_params[]` indexado por `enum movement`. Ejemplo para `SPEED_HAKI` (`MOVE_LEFT_90`):

| Parámetro | Valor | Significado |
|---|---|---|
| `start` | −68.8 mm | El perfil empieza 68.8 mm **antes** del sensing point de entrada → reduce el tramo recto previo |
| `end` | −68.8 mm | El perfil termina 68.8 mm **después** del sensing point de salida → reduce el tramo recto posterior |
| `linear_speed` | 2745 mm/s | Velocidad lineal durante el giro |
| `max_angular_speed` | 20.33 rad/s | Velocidad angular máxima |
| `transition` | 63.37 ms | Duración de la rampa sinusoidal de aceleración/deceleración |
| `arc` | 131.40 ms | Duración del giro a velocidad angular constante |
| `sign` | −1 | Giro a la izquierda |

### Significado geométrico

El punto de referencia es la **línea divisoria de casillas** (sensing point):

```mermaid
flowchart LR
    subgraph road[" "]
        direction LR
        A["tramo recto<br>reducido<br>← start (−) →"]
        B["sensing point<br>entrada"]
        C["sensing point<br>salida"]
        D["tramo recto<br>reducido<br>← end (−) →"]
    end
    subgraph turn["perfil de giro"]
        direction LR
        T1["transition<br>63 ms"]
        T2["arc<br>131 ms"]
        T3["transition<br>63 ms"]
        T1 --> T2 --> T3
    end
    A --- B
    C --- D
    B -.-> T1
    T3 -.-> C
```

- **`start` negativo**: el perfil comienza antes del sensing point → el tramo recto previo se **reduce** (el robot empieza a girar antes de cruzar la línea divisoria).
- **`start` positivo**: el perfil comienza después del sensing point → el tramo recto previo se **alarga** (el robot ya ha entrado en la celda cuando empieza a girar).
- **`end` negativo**: el perfil termina después del sensing point → el tramo recto posterior se **reduce**.
- **`end` positivo**: el perfil termina antes del sensing point → el tramo recto posterior se **alarga**.
- **`transition`**: perfil sinusoidal de aceleración angular (entrada) y deceleración (salida), duración en ms.
- **`arc`**: segmento central a velocidad angular constante, duración en ms.

---

## Perfiles de Aceleración

### Aceleración Lineal

```c
if (ideal_speed < target_speed) {
    if (ideal_speed < speed_hard)
        accel = accel_hard;    // Fase 1: agresiva
    else
        accel = accel_soft;    // Fase 2: suave (reduce slip)
    ideal_speed += accel / 1000;  // 1000 = CONTROL_FREQUENCY_HZ
}
```

### Frenada

```c
if (ideal_speed > target_speed) {
    ideal_speed −= break_accel / 1000;
}
```

### Distancia de Frenada

```c
calc_straight_to_speed_distance(current_speed, target_speed)
// Usa break_accel para calcular distancia necesaria
```

⚠️ Usa `ideal_linear_speed` en lugar de `measured_linear_speed`. Ver [MV-05](17-known-issues.md#mv-05).

---

## Degradación de Velocidad

En `move_run_sequence()`, antes de ejecutar un giro:

```c
while (distance + end_offset < required_braking_distance) {
    if (speed_strategy <= SPEED_NORMAL) break;  // mínimo
    turn = kinematics_settings[−−speed_strategy].turns[...];  // bajar nivel
}
```

La velocidad de giro se **degrada** (reduce) si no hay suficiente distancia para frenar. Pero **nunca se optimiza hacia arriba** si sobra espacio. Ver [MV-09](17-known-issues.md#mv-09).

---

*Documento generado el 2026-06-12. Ver también [Movimiento](04-movement.md), [Control PID](06-control-system.md), [Floodfill](05-floodfill.md).*

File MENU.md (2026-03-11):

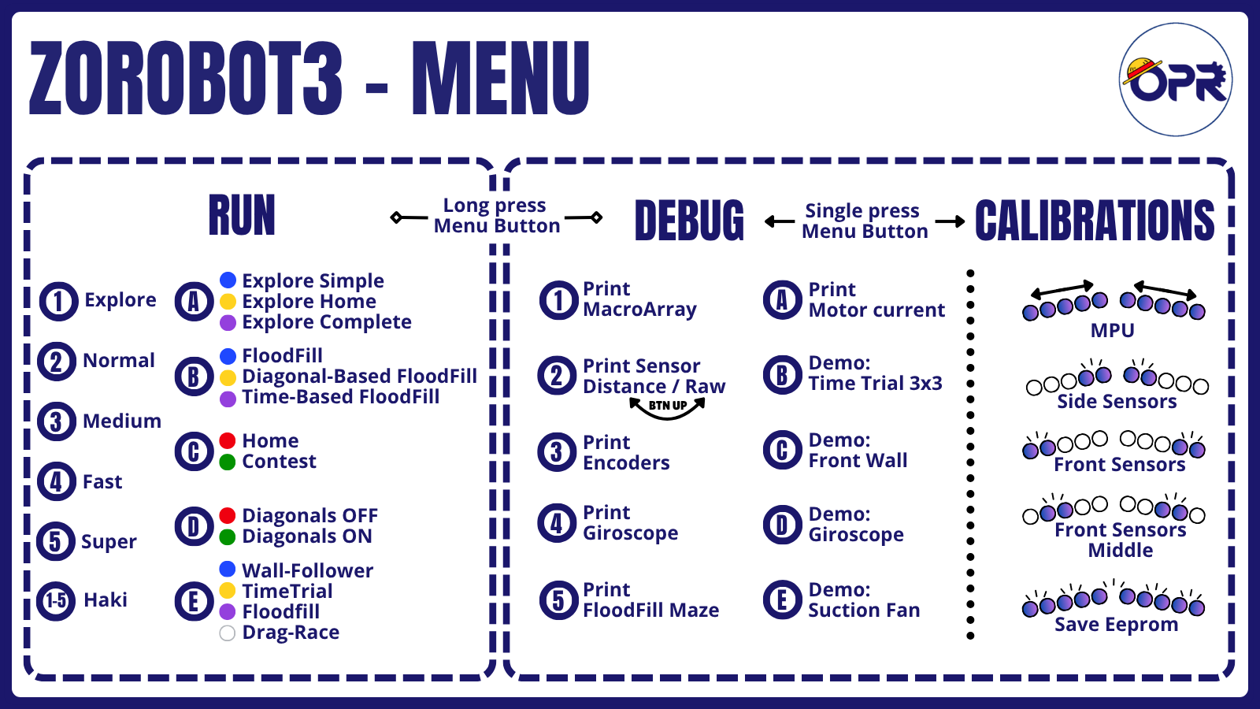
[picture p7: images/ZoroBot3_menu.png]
ZoroBot3 - Menu ZoroBot3 Menú


# Operativa General

## Tipos de Ejecución

- **EXPLORE**: Tapando el led frontal derecho:
- **EXPLORE & RUN**: Tapando el led frontal derecho y, posteriormente, el led frontal izquierdo.
- **RUN**: Tapando el led frontal izquierdo.

## Tipos de Mapeo

- **EXPLORE_SIMPLE**: Mapea hasta llegar por primera vez a **GOAL**.
- **EXPLORE_HOME**: Mapea hasta llegar por primera vez a **GOAL** y luego mapea volviendo a **HOME**.
- **EXPLORE_COMPLETE**: Mapea hasta que no queden casillas sin visitar para la solución más óptima del algoritmo de mapeo seleccionado.

## Condiciones de comportamiento

- **EXPLORE_SIMPLE** y **EXPLORE_COMPLETE** volverán a la casilla de **HOME** al finalizar el mapeo _solo si_ se trata de una ejecución **EXPLORE & RUN**. En caso contrario, el robot se detendrá en **GOAL** o en la última casilla necesaria para la ruta óptima.
- **EXPLORE_HOME** siempre vuelve hasta la casilla de **HOME** aunque ya haya visitado todo el camino correspondiente.
- Se puede modificar el tipo de mapeo después del primer **EXPLORE & RUN**, por ejemplo para completar el mapeo existente en búsqueda de la ruta más óptima para un **RUN** posterior. (ver advertencias importantes)
- Al terminar cada acción de **RUN** el robot se detendrá en la casilla de **GOAL** esperando a ser recogido.

## Advertencias importantes

- **Se requiere reiniciar el robot** después de la ejecución de cada tipo de inicio (**EXPLORE**, **EXPLORE & RUN**, **RUN**).
- Si se pretende hacer un **EXPLORE_COMPLETE** como refinamiento de un mapeo anterior y se ha reiniciado el robot, **es necesario pulsar el botón de menú** una vez el robot esté en modo iniciando (con el RGB en rojo esperando orden de arrancar) para que el led rojo de menú se apague y **no se borre todo el mapeo anterior**.

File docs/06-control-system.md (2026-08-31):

# Sistema de Control PID

## Arquitectura de Control

`control_loop()` en [`control.c:351-615`](../source_code/src/control.c#L351-L615) se ejecuta a **1 kHz** desde el SysTick ISR. Implementa 7 lazos PID en cascada para controlar velocidad lineal, velocidad angular y correcciones basadas en sensores.

```mermaid
flowchart LR
    subgraph inputs["Señales de entrada"]
        direction TB
        A["target_linear_speed"]
        B["ideal_angular_speed"]
        C["side_sensors"]
        D["front_angle"]
        E["front_distance"]
        F["front_diagonal"]
    end

    subgraph pids["6 Lazos PID"]
        direction TB
        P1["PID lineal"]
        P2["PID angular"]
        P3["PID lateral"]
        P4["PID ángulo front"]
        P5["PID dist front"]
        P6["PID diag front"]
    end

    A --> P1
    B --> P2
    C --> P3
    D --> P4
    E --> P5
    F --> P6

    P1 --> SUM["linear +<br>angular<br>voltage"]
    P2 --> SUM
    P3 --> SUM
    P4 --> SUM
    P5 --> SUM
    P6 --> SUM

    SUM --> PWM["voltage_to_pwm()"]
    PWM --> MOTORS["set_motors_pwm(L, R)"]
```

---

## Lazos PID

### 1. PID Lineal (`KPI_LINEAR`)

```c
linear_error = ideal_linear_speed − measured_linear_speed
```

Controla la velocidad lineal del robot. `measured_linear_speed` es el promedio de la velocidad de ambas ruedas (encoders).

### 2. PID Angular (`KPI_ANGULAR`)

```c
angular_error = ideal_angular_speed − measured_angular_speed
```

Controla la velocidad angular. `measured_angular_speed = −lsm6dsr_get_gyro_z_radps()` (giroscopio, signo negado).

### 3. PID Lateral (`KPI_SIDE_SENSORS`)

```c
side_error = get_side_sensors_error()
```

Corrige el centrado entre paredes laterales. Ver [Sensores - Error Lateral](03-sensors.md#error-lateral-get_side_sensors_error-centrado-entre-paredes).

### 4. PID Ángulo Frontal (`KPI_FRONT_ANGLE_SENSORS`)

```c
front_angle_error = get_front_sensors_angle_error()  // dist_L − dist_R
```

Corrige la orientación respecto a la pared frontal.

### 5. PID Distancia Frontal (`KPI_FRONT_DISTANCE_SENSORS`)

```c
front_distance_error = measured_front_dist − ideal_front_distance
```

Mantiene distancia constante a la pared frontal (usado en `keep_front_distance()`).

### 6. PID Distancia Frontal Raw (`KPI_FRONT_RAW_DISTANCE_SENSORS`)

Similar al anterior pero usando valores raw del ADC (modo `USE_RAW_SENSORS`).

### 7. PID Diagonal Frontal (`KPI_FRONT_DIAGONAL_SENSORS`)

```c
diagonal_error = get_front_sensors_diagonal_error()
```

Corrige la trayectoria en aproximaciones diagonales.

---

## Fórmula PID

Para cada lazo:

```
output = kp × error + ki × ∫error + kd × (error − last_error)
```

Donde:
- `∫error` es la suma acumulada del error (integrador)
- `(error − last_error)` es la derivada discreta

### Combinación de Voltajes

```c
linear_voltage  = PID_linear + PID_front_distance + PID_front_raw_distance
angular_voltage = PID_angular + PID_side + PID_front_angle + PID_front_diagonal

voltage_left  = linear_voltage + angular_voltage
voltage_right = linear_voltage − angular_voltage
```

### ⚠️ Anti-Windup

Los 6 integradores acumulan error sin clamping. Si los motores están saturados pero no alcanzan la velocidad deseada, el error se acumula. Al liberarse la condición, el overshoot puede desestabilizar el robot. Ver [MV-01](17-known-issues.md#mv-01).

---

## Compensación de Batería

```c
pwm = voltage / battery_voltage × MOTORES_MAX_PWM
```

Compensa variaciones de voltaje de batería para mantener el par motor constante. A menor batería, mayor PWM para la misma velocidad.

---

## Rampas de Aceleración

`update_ideal_linear_speed()` aplica aceleración progresiva hacia `target_linear_speed`:

```c
if (ideal < target) {
    accel = (ideal < speed_hard) ? accel_hard : accel_soft;
    ideal += accel / CONTROL_FREQUENCY_HZ;  // 1000
}
```

- **accel_hard**: aceleración inicial (más agresiva)
- **accel_soft**: aceleración tras superar `speed_hard` (más suave)
- **break_accel**: deceleración (frenada)

Las estrategias de velocidad más altas (FAST, SUPER, HAKI) usan aceleración en dos etapas para evitar deslizamiento.

---

## Detección de Saturación

### Saturación de PWM

```c
if (abs(pwm) >= MOTORES_SATURATION_PWM)   // 1000 de 1024
    saturation_count++;
else
    saturation_count = 0;
```

`MAX_MOTOR_SATURATION_COUNT = 100` → 100 ms de saturación continua → parada de emergencia.

### Saturación Angular

```c
if (abs(encoder_angular_speed) >= MOTORES_SATURATION_ANGULAR_SPEED)  // 50 rad/s
    angular_saturation_count++;
```

`MAX_MOTOR_ANGULAR_SATURATION_COUNT = 60` → 60 ms → parada de emergencia.

### Acción de Emergencia

1. Motores → 0
2. Ventilador → 0
3. LED RGB parpadea (rojo = PWM, azul = angular)
4. Si pasan 3 segundos → `set_race_started(false)`

---

## Control de Ventilador

El ventilador de succión también tiene control con rampa:

```c
update_fan_speed():
    if (ideal < target) ideal += fan_speed_accel / 1000
    set_fan_speed(ideal)
```

La velocidad del ventilador depende de la estrategia y del voltaje de batería (2S vs 3S).

---

## Diagrama de Cascada

```mermaid
flowchart TD
    subgraph CL["control_loop() @ 1 kHz"]
        direction TB
        A["Rampa aceleración<br>ideal += accel / 1000"]
        B["Error = ideal − measured<br>(encoders)"]
        C["PID Lineal<br>kp·e + ki·∫e + kd·(e − e_prev)"]
        D["Σ correcciones angulares:<br>  + PID angular (gyro)<br>  + PID lateral (side sensors)<br>  + PID ángulo frontal<br>  + PID diagonal frontal"]
        E["voltage_L = linear + angular<br>voltage_R = linear − angular"]
        F["PWM = voltage / Vbat × MAX_PWM"]
        G["set_motors_pwm()<br>check_saturation()"]

        A --> B --> C
        C -->|"linear_voltage"| D
        D -->|"angular_voltage"| E
        E --> F --> G
    end
```

---

*Documento generado el 2026-06-12. Ver también [Movimiento](04-movement.md), [Sensores](03-sensors.md), [Cinemática](15-kinematics.md). Issues: [MV-01, MV-10](17-known-issues.md).*

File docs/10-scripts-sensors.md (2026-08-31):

# Scripts: Calibración de Sensores IR

Herramienta offline para calibrar los sensores infrarrojos del robot. Calcula las
constantes `(a, b, c)` del modelo logarítmico empírico que convierte lecturas
ADC en distancia real (mm).

| Característica | Detalle |
|---|---|
| **Script** | `scripts/sensors-profiles/sensors-profiles.ipynb` |
| **Tipo** | Jupyter Notebook |
| **Dependencias** | `numpy`, `pandas`, `matplotlib`, `scipy` |
| **Salida** | Constantes `(a, b, c)` para cada sensor → se copian a `sensors.c` |

---

## Modelo Matemático

### Ecuación

```
distance (m) = a / ln(raw + c) - b
```

| Parámetro | Descripción |
|---|---|
| `raw` | Valor ADC (0–4095), lectura diferencial: sensor ON − sensor OFF |
| `a` | Factor de escala — controla la forma de la curva logarítmica |
| `b` | Offset vertical — desplaza la curva en distancia |
| `c` | Offset horizontal — compensa el offset del sensor, evita colapso del logaritmo |

### Justificación física

Los sensores IR de reflectancia siguen aproximadamente la ley de la inversa del
cuadrado: `raw ∝ 1/d²`, o equivalentemente `d ∝ 1/√raw`. El modelo
`a/ln(raw+c) - b` es una aproximación empírica con asíntotas similares pero
mejor comportamiento en los extremos del rango.

### Conversión en el firmware

```c
// sensors.c:505-509
int16_t ln_index = (raw_filtered + calib.c) / 4;
float ln = get_ln_value(ln_index);
int16_t distance_mm = (int16_t)((calib.a / ln - calib.b) * 1000.0f);
```

El firmware usa una **LUT de 1024 entradas** que almacena `ln(index × 4)`. La
división entera por 4 introduce un error de cuantificación < 0.5% en distancia.
El notebook simula esta cuantificación y reporta el error introducido.

---

## Estructura del Notebook

| Celda | Contenido |
|---|---|
| 0 | Imports: `numpy`, `pandas`, `matplotlib`, `scipy.optimize.curve_fit` |
| 1 | Datos de calibración: arrays de 26 valores raw por sensor, `ACTIVE_DATASETS`, `PLOT_MODE` |
| 2 | Grid 2×2 con valores raw de todos los robots superpuestos |
| 3 | Funciones: `raw_to_distance()`, `raw_to_distance_firmware()`, `estimate_p0()`, `compute_metrics()` |
| 4 | Selección de rangos de ajuste frontales y laterales |
| 5 | Ajuste de curvas con `curve_fit` (Levenberg-Marquardt), imprime `a,b,c ± incertidumbre` + R²/RMSE |
| 6 | Análisis de error: `.describe()`, RMSE por rangos, error de cuantificación LUT |
| 7 | Gráficas de error y curvas ajustadas |
| 8 | Structs C para copiar al firmware, agrupados por robot |

---

## Flujo de Trabajo

```mermaid
flowchart TD
    A[Tomar medidas: raw vs distancia] --> B[Añadir datos al notebook]
    B --> C[Ajustar rangos de interés]
    C --> D[Ejecutar curve_fit]
    D --> E{¿RMSE < 5 mm?}
    E -->|Sí| F[Validar error de LUT]
    E -->|No| G[Revisar datos o p0]
    G --> D
    F --> H{¿Error LUT < 3 mm?}
    H -->|Sí| I[Copiar structs C a sensors.c]
    H -->|No| J[Reajustar con modelo firmware]
    J --> D
```

### Rangos de ajuste

| Sensor | Rangos de ajuste | Rango excluido |
|---|---|---|
| Frontales | 20–70 mm y 100–150 mm | 70–100 mm |
| Laterales | 5–90 mm y 100–170 mm | 90–100 mm |

Los rangos excluidos son distancias de transición donde la precisión es menos
crítica para la navegación.

### Ajuste de curvas

Se usa `scipy.optimize.curve_fit` con Levenberg-Marquardt. `estimate_p0()`
calcula valores iniciales a partir de los extremos del rango. Cada sensor se
ajusta independientemente con bounds específicos:

| Tipo | Bounds `a` | Bounds `b` | Bounds `c` |
|---|---|---|---|
| Frontales | [−10, 10] | [−1, 1] | [−200, 200] |
| Laterales | [−5, 5] | [−2, 2] | [−300, 300] |

---

## Integración con el Firmware

### Dónde se copian las constantes

[`source_code/src/sensors.c`](../source_code/src/sensors.c) — función
`set_sensors_robot_calibration()` (línea 67).

Las constantes se almacenan por versión de robot (`ZOROBOT3_A`, `ZOROBOT3_B`,
`ZOROBOT3_C`). La celda 8 del notebook imprime los structs C listos para copiar.

### Procesamiento en tiempo real

En [`update_sensors_magics()`](../source_code/src/sensors.c#L486), cada ciclo:

1. Cálculo de `raw_filtered` (mediana de 3 lecturas)
2. `ln_index = (raw_filtered + c) / 4`
3. Búsqueda en LUT: `ln = get_ln_value(ln_index)`
4. `distance_mm = (a / ln - b) × 1000`
5. Aplicación de offsets geométricos (`ROBOT_FRONT_LENGTH`, `ROBOT_MIDDLE_WIDTH`)
6. Filtro paso-bajo con α adaptativo (0.2 normal, 0.6 para cambios grandes)
7. Aplicación del offset de calibración de EEPROM (`sensors_distance_offset`)

---

## Guía de Uso

### Requisitos

```bash
pip install numpy pandas matplotlib scipy
```

### Procedimiento para un robot nuevo

1. **Tomar medidas**: colocar el robot a distancias conocidas (0–250 mm, pasos
   de 10 mm) y registrar el raw de cada sensor
2. **Añadir datos**: nueva entrada en `DATASETS` (celda 1) con arrays de 26
   valores (orden: 250 mm → 0 mm)
3. **Ajustar rangos** en celda 4 si es necesario
4. **Ejecutar `Cell > Run All`**
5. **Verificar**: RMSE < 5 mm en rangos ajustados, `a` no negativo, error LUT < 3 mm
6. **Copiar al firmware**: salida de la celda 8 → `set_sensors_robot_calibration()`

### Solución de problemas

| Síntoma | Causa probable | Solución |
|---|---|---|
| `a` negativo | Datos no siguen el modelo logarítmico | Revisar mediciones, verificar que `raw` decrece con la distancia |
| Error grande en rangos excluidos | Curva no extrapola bien | Ampliar rangos de ajuste en celda 4 |
| RMSE > 10 mm todos los sensores | Datos ruidosos o mal tomados | Repetir mediciones, verificar iluminación ambiental |
| LUT da resultados distintos | Error de cuantificación | Si > 3 mm, usar `raw_to_distance_firmware()` en `curve_fit` |

---

*Documento generado el 2026-08-25. Ver también [Sensores](03-sensors.md), [Calibración](09-calibration.md), [EEPROM](11-eeprom.md), [Problemas Conocidos](17-known-issues.md#sp-01).*

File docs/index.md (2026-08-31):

# ZoroBot3 — Documentación Técnica

> Robot micromouse de alto rendimiento con STM32F4, encoders magnéticos de alta resolución, ventilador de succión y 4 sensores infrarrojos.

ZoroBot3

---

## 🏆 Palmarés

| 🥇 | 🥈 | 🥉 |
|:--:|:--:|:--:|
| **8** | **0** | **0** |

### Resultados por Evento

| Evento | Categoría | Posición | Año |
|---|---|:---:|:---:|
| 🇵🇹 **Micromouse Portuguese Contest** | Micromouse Classic | 🥇 | 2026 |
| 🇷🇴 **RoboChallenge** | Maze | 🥇 | 2025 |
| 🇪🇸 **OSHWDem** | Micromouse Classic | 🥇 | 2025 |
| 🇵🇹 **Micromouse Portuguese Contest** | Micromouse Classic | 🥇 | 2025 |
| 🇵🇹 **Micromouse Portuguese Contest** | Time Trial | 🥇 | 2025 |
| 🇷🇴 **RoboChallenge** | Maze | 🥇 | 2024 |
| 🇪🇸 **OSHWDem** | Micromouse Classic | 🥇 | 2024 |
| 🇪🇸 **OSHWDem** | Micromouse Wall-Follower | 🥇 | 2023 |

---

## ⚙️ Hardware

- **Microcontrolador**: STM32F405RGT6 @168MHz
- **Driver de motores**: MP6551 @20kHz
- **Giroscopio**: LSM6DSRTR 4000dps
- **Encoders**: AS5145B-HSST (12-bit, lectura en cuadratura por hardware)
- **Regulador**: CN3903 + LDO ME611C33M5G
- **Sensores IR**: 4× SFH-4550 (emisores) + 4× ST-1KL3A (receptores) + TSSP77038TR (38kHz)
- **Batería**: LiPo 2S 260mAh 35-70C Turnigy nano-tech
- **Tracción**: 2× Motores Coreless 8520 7.4v, chasis de PCB, gomas Kyosho

Chasis ZoroBot3 - Chasis

---

## 💻 Software

- Programado en **C11** con VSCode, PlatformIO y **LibOpenCM3**.
- Valores analógicos leídos por **DMA**, procesados cada **1 ms**.
- Sensores IR gestionados por máquina de estados a **16 kHz** con filtrado de luz ambiente.
- Encoders en **cuadratura por hardware** mediante timers, MPU por **SPI**.
- **7 lazos PID en cascada** (velocidad lineal, angular, control frontal, control lateral) ejecutados cada 1 ms.
- Reseteo de posición por pérdida de pared lateral.
- Curvas con perfiles de giro de **aceleración senoidal**.
- Algoritmos: seguimiento de pared, exploración, **Floodfill basado en pesos cinemáticos** y movimientos hardcodeados.

---

## 📚 Documentación Detallada

- **[Hardware](01-hardware.md)** — MCU, sensores, motores, encoders, batería, chasis, versiones del robot
- **[Arquitectura Software](02-software-architecture.md)** — Bucle principal, SysTick ISR, flujo de carrera, exploración
- **[Sensores](03-sensors.md)** — Máquina de estados ADC, linealización, detección de paredes, histéresis
- **[Movimiento](04-movement.md)** — Tipos de movimiento, perfiles de giro, speed run, wall loss correction
- **[Floodfill](05-floodfill.md)** — Algoritmos BASIC/DIAGONAL/TIME_BASED, BFS, path following
- **[Control PID](06-control-system.md)** — 7 lazos en cascada, anti-windup, compensación de batería
- **[Menú](07-menu-system.md)** — Navegación, selección de algoritmo, configuración de velocidad
- **[Debug](08-debug-system.md)** — LEDs, RGB, USART, funciones de debug
- **[Calibración](09-calibration.md)** — Calibración frontal/lateral, giroscopio, persistencia en EEPROM
- **[Scripts: Calibración Sensores](10-scripts-sensors.md)** — Herramienta Jupyter de perfiles de linealización IR y magics
- **[EEPROM](11-eeprom.md)** — Almacenamiento, checksum, maze persistente
- **[Encoders y Giroscopio](12-encoders-gyro.md)** — AS5145B-HSST, LSM6DSR, integración angular
- **[Batería y LEDs](13-battery-leds.md)** — Monitorización de voltaje, divisor de tensión, LEDs de estado
- **[Simulador MMSIM](14-simulator.md)** — API de paredes virtuales, estimación de tiempo
- **[Cinemática](15-kinematics.md)** — Estrategias de velocidad, perfiles de aceleración, parámetros de giro
- **[Scripts: Perfiles de Giro](16-scripts-turn-profiles.md)** — Generación offline de perfiles de giro sinusoidales
- **[Problemas Conocidos](17-known-issues.md)** — Issues documentados con IDs, impacto y soluciones

---

## 🔧 Stack Tecnológico

| Componente | Detalle |
|---|---|
| **MCU** | STM32F405RGT6 @ 168 MHz (ARM Cortex-M4F) |
| **Framework** | LibOpenCM3 + PlatformIO |
| **Lenguaje** | C11 |
| **Compilador** | GCC ARM Embedded (arm-none-eabi-gcc) |
| **IDE** | VSCode |
| **Control de versiones** | Git |

---

## 🎥 Vídeos

### Micromouse Portuguese Contest 2026 — 🥇
<video src="https://github.com/user-attachments/assets/5a7cf803-e31e-463a-afa9-e5784b378937" width="50%" controls></video>

### OSHWDem 2025 — 🥇
<video src="https://github.com/user-attachments/assets/332fd117-6600-4692-b59f-4b1154166f3f" width="50%" controls></video>

### Micromouse Portuguese Contest 2025 — 🥇
<video src="https://github.com/user-attachments/assets/cf21e942-3fe0-4065-8892-fa3d181a9791" width="50%" controls></video>

### RoboChallenge 2024 — 🥇
<video src="https://github.com/user-attachments/assets/a8c53e97-a756-4934-9c83-6c93fda1b235" width="50%" controls></video>

### OSHWDem 2024 — 🥇
<video src="https://github.com/user-attachments/assets/a70629e6-34b6-473f-afb0-14d8290bd128" width="50%" controls></video>

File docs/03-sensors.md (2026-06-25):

# Sistema de Sensores

## Hardware

4 sensores infrarrojos con lectura diferencial para filtrar luz ambiente:

| Sensor | ID | Canal ADC | GPIO Emitter | Función |
|---|----|---|---|---|
| Front Left | `SENSOR_FRONT_LEFT_WALL_ID` (0) | ADC_CHANNEL10 (PC0) | PA0 | Pared frontal (izquierda) |
| Front Right | `SENSOR_FRONT_RIGHT_WALL_ID` (1) | ADC_CHANNEL13 (PC3) | PA3 | Pared frontal (derecha) |
| Side Left | `SENSOR_SIDE_LEFT_WALL_ID` (2) | ADC_CHANNEL12 (PC2) | PA2 | Pared lateral izquierda |
| Side Right | `SENSOR_SIDE_RIGHT_WALL_ID` (3) | ADC_CHANNEL11 (PC1) | PA1 | Pared lateral derecha |

- **Emisor**: SFH-4550 (GaAs, 860 nm)
- **Receptor**: ST-1KL3A (fototransistor, filtro luz visible)
- **Principio**: `lectura útil = sensors_on − sensors_off` (filtrado de luz ambiental)
- **Ley física**: `reading ≈ k / distance²`

### Canales ADC Auxiliares

| Canal | GPIO | Función |
|---|---|---|
| ADC_CHANNEL4 | PA4 | Voltaje de batería |
| ADC_CHANNEL14 | PC4 | Corriente motor izquierdo |
| ADC_CHANNEL15 | PC5 | Corriente motor derecho |
| ADC_CHANNEL8 | PB0 | Botón de menú |

---

## Arquitectura Software

Archivos: [`sensors.h`](../source_code/include/sensors.h), [`sensors.c`](../source_code/src/sensors.c)

### Estados

```c
static bool sensors_enabled = false;        // Sensores activados
static bool sensors_taking_values = false;  // Toma de valores puntual (debug)
```

### Datos por sensor

| Variable | Descripción |
|---|---|
| `sensors_raw[4]` | Valor crudo filtrado (on − off) |
| `sensors_on[4]` | Lectura ADC con LED encendido |
| `sensors_off[4]` | Lectura ADC con LED apagado |
| `sensors_distance[4]` | Distancia linealizada en mm |
| `sensors_distance_offset[4]` | Offset de calibración |
| `sensors_raw_wall_detection_threshold[4]` | Umbral raw para detección |
| `sensors_middle_target_distance[4]` | Distancia objetivo centro celda |

---

## Máquina de Estados ADC

`sm_emitter_adc()` ([`sensors.c:214-251`](../source_code/src/sensors.c#L214-L251)) ejecuta una máquina de 4 estados por sensor, llamada a 16 kHz:

```
Estado 1: Leer ADC (LED OFF) → Encender LED → Estado 2
Estado 2: Iniciar conversión ADC → Estado 3
Estado 3: Leer ADC (LED ON) → Apagar LED → Estado 4
Estado 4: Iniciar conversión ADC → Siguiente sensor → Estado 1
```

**Secuencia completa** (8 pasos por ciclo de 4 sensores):
```
FL_off → FL_on → FR_off → FR_on → SL_off → SL_on → SR_off → SR_on → FL_off...
```

### Timing

- Clock ADC2: ~42 MHz (PCLK2/2)
- Tiempo de conversión 12-bit: ~0.64 µs (15 ciclos sample + 12 ciclos conv)
- Intervalo entre estados (16 kHz): 62.5 µs
- **Margen de seguridad: ~97x** → no hay riesgo de solapamiento de conversiones.

---

## Linealización y Conversión a Distancia

### Proceso (`update_sensors_magics()`, [`sensors.c:462-525`](../source_code/src/sensors.c#L462-L525))

1. **Señal diferencial**: `raw = sensors_on − sensors_off`. Si `on ≤ off` → se descarta.

2. **Mediana de 3 muestras** (filtro anti-spike): `raw_filter = triplet_median(raw_ring[sensor][0], raw_ring[sensor][1], raw_ring[sensor][2])`. Elimina spikes de EMI de motores.

3. **Índice logarítmico**: `ln_index = (raw_filter + c) / 4`
   - Parámetro `c` específico por sensor y versión. **Clampeado a [0, 1023]** para evitar OOB.
   - Paso de 4 porque la LUT tiene resolución `ADC_RESOLUTION / 4 = 1024` entradas.

4. **Logaritmo natural**: `ln = get_ln_value(ln_index)` — tabla precalculada de 1024 entradas.
   - `ln(0)` se define como `1.0` para evitar inestabilidades numéricas.

5. **Fórmula de distancia**: `dist_raw = (a / ln − b) × 1000.0`
   - Parámetros `a`, `b` son coeficientes de calibración por sensor/versión.
   - Resultado en **micrómetros** (×1000).

6. **Ajuste geométrico**: Se suma la distancia del sensor al centro del robot:
   - Frontales: `+ROBOT_FRONT_LENGTH` (48.121 mm → 48121 μm)
   - Laterales: `+ROBOT_MIDDLE_WIDTH` (35.1 mm → 35100 μm)

7. **Offset de calibración**: `+sensors_distance_offset[sensor]`.

8. **Filtro EMA adaptativo**:
   - `|delta| > 10 mm` → α = 0.6 (respuesta rápida, τ ≈ 1.7 muestras)
   - `|delta| ≤ 10 mm` → α = 0.2 (filtrado agresivo, τ ≈ 5 muestras)

---

## Detección de Paredes

### Modo Raw (`USE_RAW_SENSORS = true`)

```c
wall_detected = raw_filter > raw_threshold
```

Umbral calculado con ley física 1/d²: `threshold = raw_at_cal / (1.5)² = raw_at_cal / 2.25`.

Esto fija la distancia de detección al 150% de la distancia de calibración:
- Frontales: `d_det = 174 × 1.5 = 261 mm`
- Laterales: `d_det = 84 × 1.5 = 126 mm`

### Modo Distancia (`USE_RAW_SENSORS = false`)

```c
// Frontales
wall_detected = distance < SENSOR_FRONT_DETECTION  // 219.6 mm
// Laterales
wall_detected = distance < SENSOR_SIDE_DETECTION   // 115 mm
```

### Histéresis (Debounce)

Contador con histéresis asimétrica para evitar oscilaciones:

```mermaid
stateDiagram-v2
    [*] --> no_pared
    no_pared --> confirmando : pared detectada
    confirmando --> no_pared : pierde señal
    confirmando --> hay_pared : 4 detecciones consecutivas
    hay_pared --> perdiendo : pierde señal
    perdiendo --> hay_pared : re-detecta pared
    perdiendo --> no_pared : 6 no-detecciones consecutivas
```

- **4 detecciones consecutivas** para confirmar una pared.
- **6 no-detecciones consecutivas** para perder una pared.
- Asimetría intencionada: más difícil perder que encontrar (evita falsos negativos).

### Pared Frontal

```c
front_wall = wall_present[FL] || wall_present[FR]
```
Basta con que UNO de los dos sensores frontales detecte pared.

---

## Cálculo de Errores para Control

Todos alimentan controladores PID en `control_loop()`.

### Error Lateral (`get_side_sensors_error()`) — Centrado entre paredes

```c
left_error  = dist_left  − MIDDLE_MAZE_DISTANCE   // 84 mm
right_error = dist_right − MIDDLE_MAZE_DISTANCE
```

Lógica de selección:
| Condición | Error devuelto |
|---|---|
| Ambas paredes < 90mm | `right_error − left_error` (diferencia simétrica) |
| Solo izquierda < 90mm | `−2 × left_error` |
| Solo derecha < 90mm | `2 × right_error` |
| Izquierda > 184mm y derecha < 124mm | `2 × right_error` |
| Derecha > 184mm e izquierda < 124mm | `−2 × left_error` |
| Ninguna pared cercana | 0 |

### Error Diagonal (`get_diagonal_sensors_error()`)

Selecciona el sensor frontal más cercano y calcula su desviación de 320 mm:

```c
if (left < right && left < 320)  → −(left − 320)
if (right ≤ left && right < 320) → right − 320
```

### Error de Ángulo Frontal (`get_front_sensors_angle_error()`)

```c
error = dist_left − dist_right  // Solo si se detecta pared frontal
```

### Error Diagonal Frontal (`get_front_sensors_diagonal_error()`)

```c
left_error  = dist_left  − 320
right_error = dist_right − 320
// Devuelve right_error si es negativo, −left_error si es negativo, 0 sino
```

---

## Uso de Sensores en Movimiento

| Movimiento | Side Sensors | Front Angle | Front Distance | Front Diagonal |
|---|:---:|:---:|:---:|:---:|
| `MOVE_FRONT` (recta) | ✅ (si hay pared) | ❌ | ❌ | ❌ |
| `MOVE_LEFT`/`MOVE_RIGHT` (exploración) | ❌ | ❌ | ❌ | ❌ |
| `MOVE_LEFT_90`/etc (carrera, no diagonal) | ❌ | ❌ | ❌ | ❌ |
| Giros con entrada a 45° | ❌ | ❌ | ❌ | ✅ |
| `MOVE_HOME` (volver a inicio) | ❌ | ✅ → ❌ | ✅ (PID) | ❌ |
| `MOVE_END` | ✅ (sin pared frontal) | ❌ | ❌ | ❌ |
| `MOVE_BACK` / `MOVE_BACK_WALL` | ✅ (tras girar) | ✅ (si pared frontal) | ❌ | ❌ |
| `run_straight()` (carrera) | ✅ (desactiva si detecta pared frontal) | ❌ | ❌ | ❌ |
| `run_diagonal()` | ❌ | ❌ | ❌ | ✅ (>1 celda) |

### `keep_front_distance()`

Mantiene distancia constante a pared frontal mediante PID:
- Modo distancia: objetivo en mm, tolerancia ±2 mm, timeout configurable.
- Modo raw: objetivo en unidades raw, tolerancia ±20.
- Tras alcanzar distancia, ajusta ángulo si error ≥ 5.

### Corrección por Pérdida de Pared (`check_wall_loss_correction()`)

Durante `run_straight()`, si desaparece una pared lateral:
1. Se registra el evento (flag + toggle LED).
2. Se reajusta la distancia restante: desde posición actual hasta `WALL_LOSS_TO_SENSING_POINT_DISTANCE` (116 mm).
3. En la última celda, si pierde la pared del lado del próximo giro, usa la misma corrección.

---
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

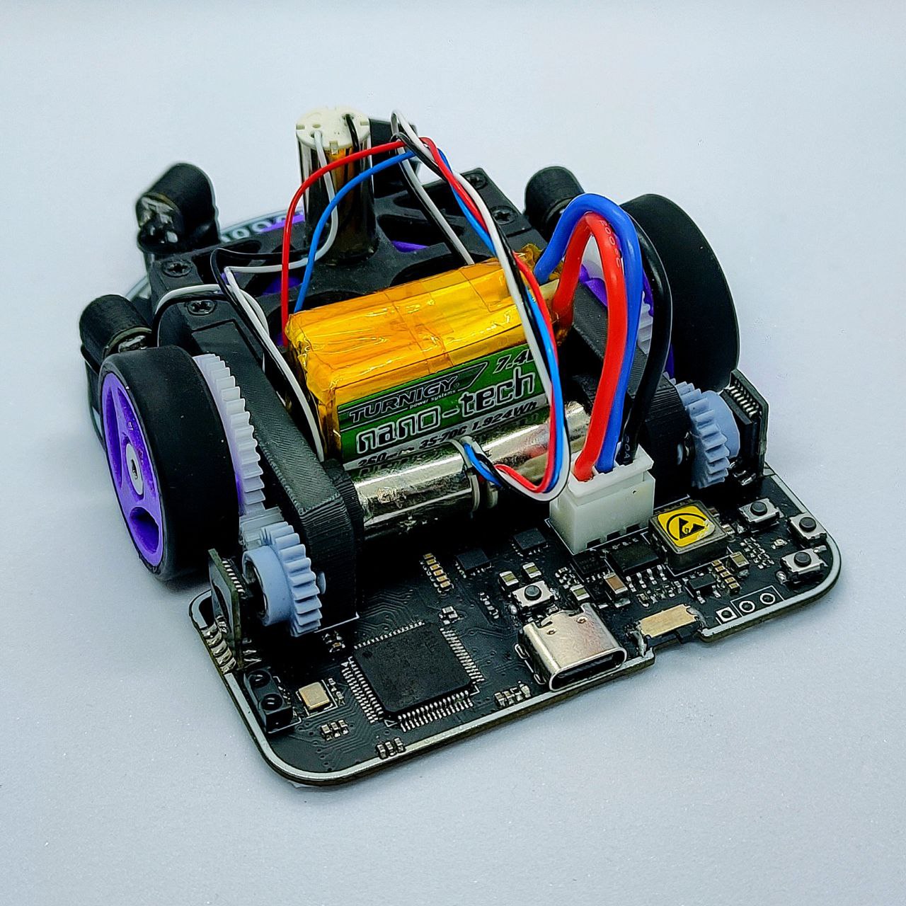
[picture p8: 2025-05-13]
images/ZoroBot3_rev2_finish_2.jpg

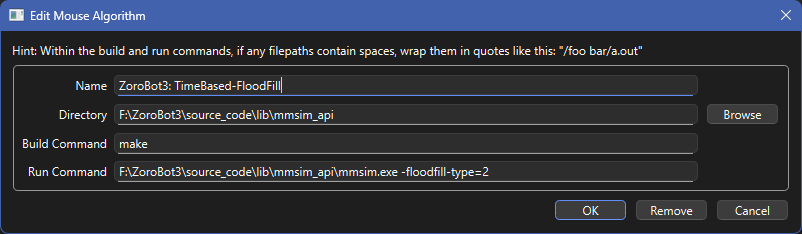
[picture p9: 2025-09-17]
images/mmsim_api_config.png

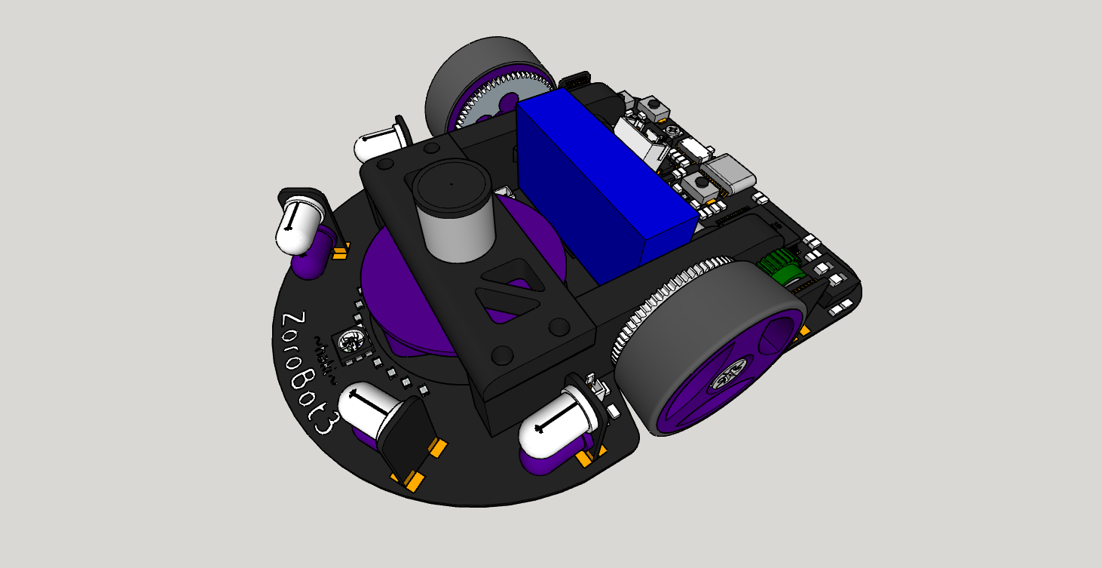
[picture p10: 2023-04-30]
images/ZoroBot3_3d_model.png

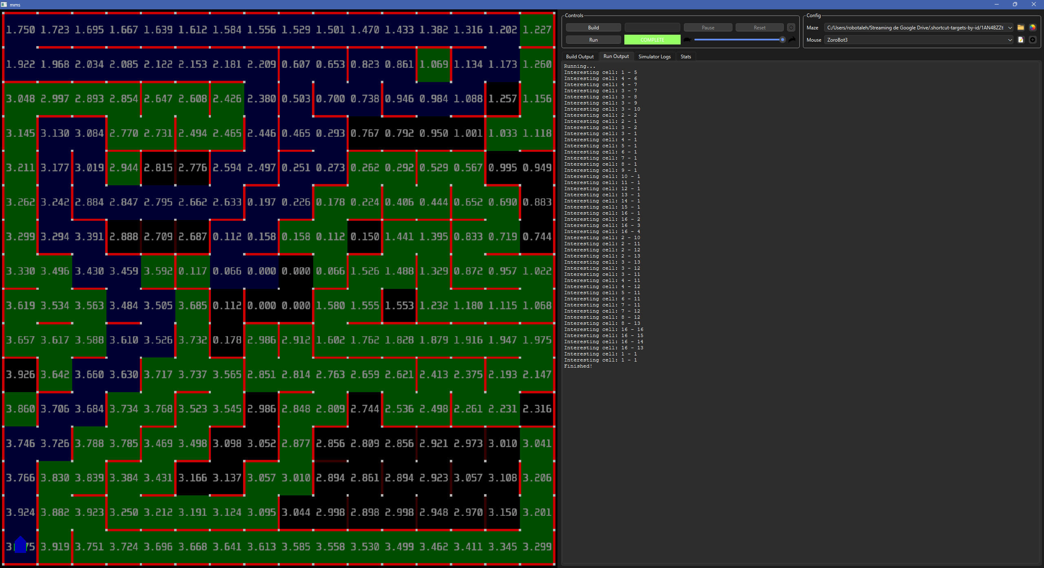
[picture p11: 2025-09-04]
images/mmsim_japan_2019.png

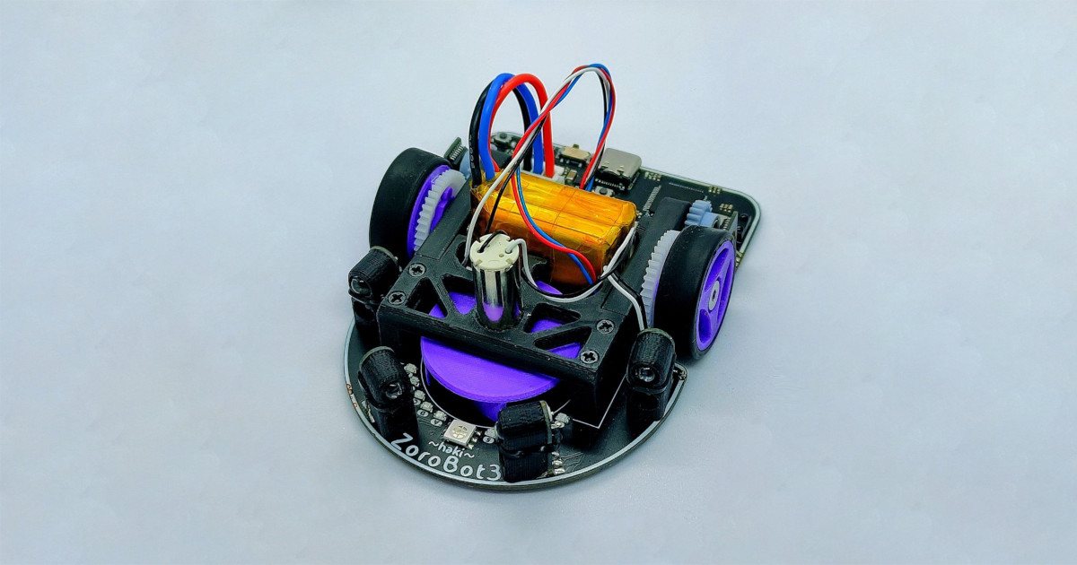
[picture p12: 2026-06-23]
docs/assets/imgs/zorobot3-social-preview.jpg

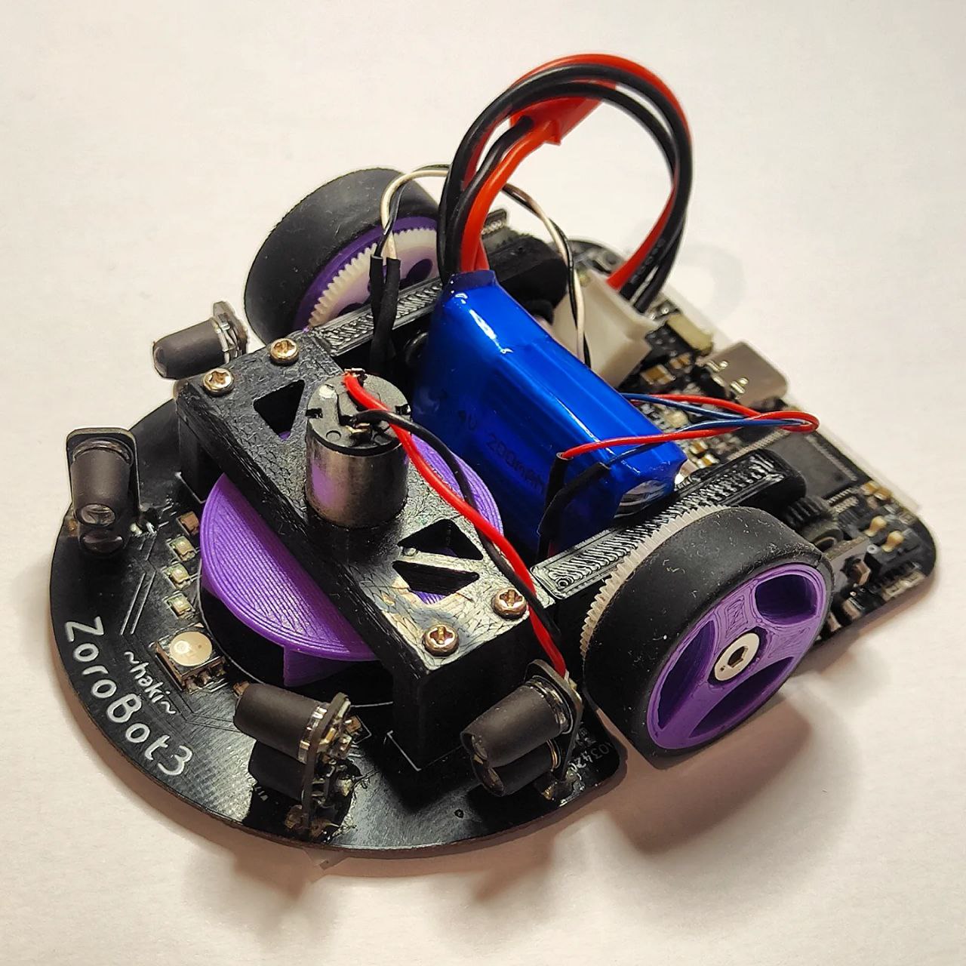
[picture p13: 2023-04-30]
images/ZoroBot3_finish_1.png

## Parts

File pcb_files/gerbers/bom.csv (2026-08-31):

Designator | Footprint | Quantity | Value | LCSC Part #
AS5145B_D1, AS5145B_I1 | Encoder_AS5145B | 2 | AS5145B-HSST
AUX_CONN1 | PinHeader_1x03_P2.54mm_Vertical | 1 | Conn_01x03_Pin
BATT1 | JST_XH_B3B-XH-A_1x03_P2.50mm_Vertical | 1 | Conn_01x03_Pin
BTN1, BTN2, BTN3, BTN_RST1 | Generic_SmallButton_6x3 | 4 | ~
C1 | 0402 | 1 | 4.7uF
C10, C11, C17, C2, C20, C21, C24, C33, C35, C37, C38, C39, C4, C40, C7, CR1, CR2, CR5, CS2, CS4, CS6, CS8, CSRAM1, CSRAM2 | 0402 | 24 | 0.1uF
C12, C19 | 0402 | 2 | 2.2uF
C13, C15 | 0402 | 2 | 20pF
C18, C22, C32, C34, CR3 | 0402 | 5 | 1uF
C23, C3, C30, C41, C42, C44, C45, C46, C47, C48, C49, C50, C51, C52, C6, C9, CS1, CS3, CS5, CS7 | 0402 | 20 | 10uF
C31, C43, C5, C8 | 0805 | 4 | 47uF
CF1, CF2 | 0402 | 2 | 220nF
CONN_SEN_FRONT_D1, CONN_SEN_FRONT_I1, CONN_SEN_PA_D1, CONN_SEN_PA_I1 | ZoroBot3_Sensors | 4 | Conn_01x04_Socket
CR4, CR7 | 0603 | 2 | 0.1uF
CR6 | 1206 | 1 | 47uF
D1, D10, D2, D3, D4, D5, D6, D7, D8, D9 | 0805 | 10 | LED
D11, D12 | 0402 | 2 | LED
D13, DS1 | 0805 | 2 | D
DATA_MPU+SRAM1 | ZoroBot3_Data_MPU | 1 | Conn_01x05_Socket
DATA_MPU1, DATA_MPU2 | ZoroBot3_Data_MPU | 2 | Conn_01x04_Socket
DC-DC1 | Texas_HTSOP-8-1EP_3.9x4.9mm_P1.27mm_EP2.95x4.9mm_Mask2.4x3.1mm_ThermalVias | 1 | ~
DEIXAME_QUE_PENSE_1 | LQFP-64_10x10mm_P0.5mm | 1 | STM32F405RGT6
ENC_D1, ENC_I1 | ZoroBot3_PCBmain_Encoder | 2 | Conn_01x05_Socket
ENC_D_CONN1, ENC_I_CONN1 | ZoroBot3_PCBmodule_encoder | 2 | Conn_01x05_Pin
IR_RECIVER1 | IR_SENSOR_SMD_TSSP77038ETR | 1 | ~
JP2 | SolderJumper-2_P1.3mm_Open_RoundedPad1.0x1.5mm | 1 | SolderJumper_2_Open
L1 | L_Wuerth_HCM-7050 | 1 | L
LED_IR1, LED_IR2, LED_IR3, LED_IR4 | LED_D5.0mm_Clear | 4 | SFH-4550
LSM6DSR1, LSM6DSR2 | Bosch_LGA-14_3x2.5mm_P0.5mm | 2 | ~
MIC1 | SOT-23-5_HandSoldering | 1 | ~
MOSFET-N-SUC1, MOSFET-N1, MOSFET-N2, MOSFET-N3, MOSFET-N4 | SOT-23 | 5 | AO3400A
MOT_D1, MOT_I1, MOT_S1 | Connector_motor_1.25_Hirose_DF13-02P-1.25DSA_1x02_P1.25mm_Vertical | 3 | Conn_01x02_Socket
PH1, PH2 | PH-MP6551GQB-P | 2 | ~
POWER_MPU1, POWER_MPU2, POWER_MPU3 | ZoroBot3_Power_MPU | 3 | Conn_01x02_Socket
POWER_SWITCH1 | Generic_Swich_ONOFF | 1 | SW_DPDT_x2
Q2 | DFN-8-1EP_3x3mm_P0.65mm_EP1.55x2.4mm | 1 | AON7423
Q3, Q4, Q5, Q6 | LED_D5.0mm_IRBlack | 4 | ST-1KL3A
R1, R10, R14, R15, R16, R2, R22, R3, R4, R5, R6, R7, R8, R9 | 0402 | 14 | 330
R11, R17, R21, R24, R25, RS11, RS12, RS5, RS6 | 0402 | 9 | 47K
R18, R30 | 0402 | 2 | 100K
R19, R26 | 0402 | 2 | 27k
R20, R23, R28, RF1, RF2 | 0402 | 5 | 1K
R27, RRAM1, RRAM2 | 0402 | 3 | 10K
R29 | 0402 | 1 | 45K
R31 | 0402 | 1 | 60k
RCM1, RCM2, RCM3, RCM4 | 0402 | 4 | 5k
RGB1 | LED_RGB_5050-6 | 1 | LED_RGB
RS1, RS2, RS7, RS8 | 0805 | 4 | 33
RS10, RS9 | 0805 | 2 | 1.5K
RS3, RS4 | 0805 | 2 | 3.3K
SEN_FRONT_D1, SEN_FRONT_I1, SEN_PARED_D1, SEN_PARED_I1 | ZoroBot3_Main_sensors | 4 | Conn_01x04_Socket
SRAM1, SRAM2 | TSSOP-8_4.4x3mm_P0.65mm | 2 | 23AA04M-I/ST
USB1 | USB-C ST-Link USART | 1 | ~
Y1 | Crystal_SMD_TXC_7M-4Pin_3.2x2.5mm | 1 | Crystal_GND24

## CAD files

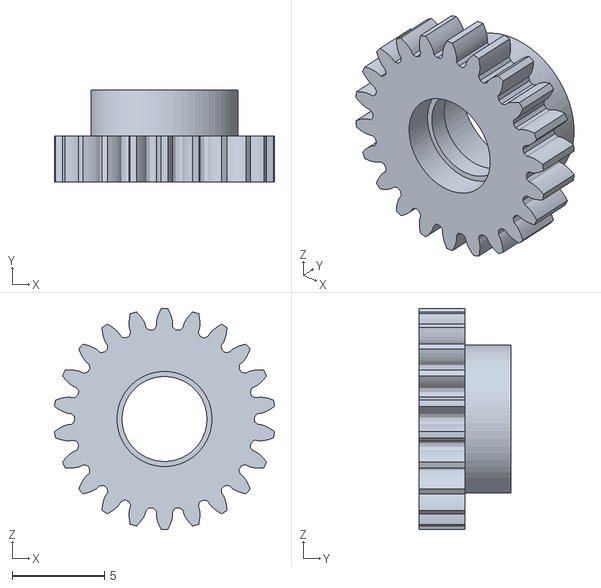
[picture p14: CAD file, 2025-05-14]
3d_model/stl_files/Part Studio - Spur gear (22 teeth).stl
11.9 x 5.00 x 12.0

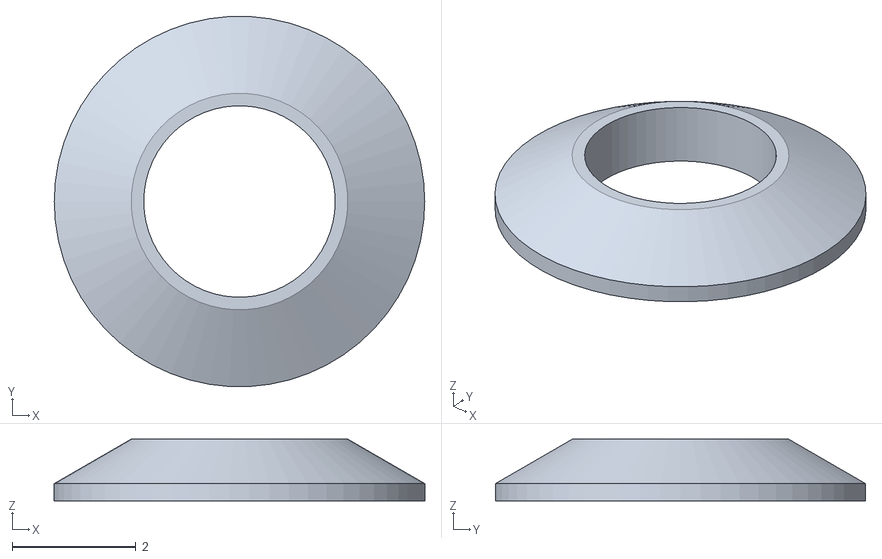
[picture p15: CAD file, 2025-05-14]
3d_model/stl_files/Part Studio - Arandela M3 -editada-.stl
6.00 x 5.99 x 1.00

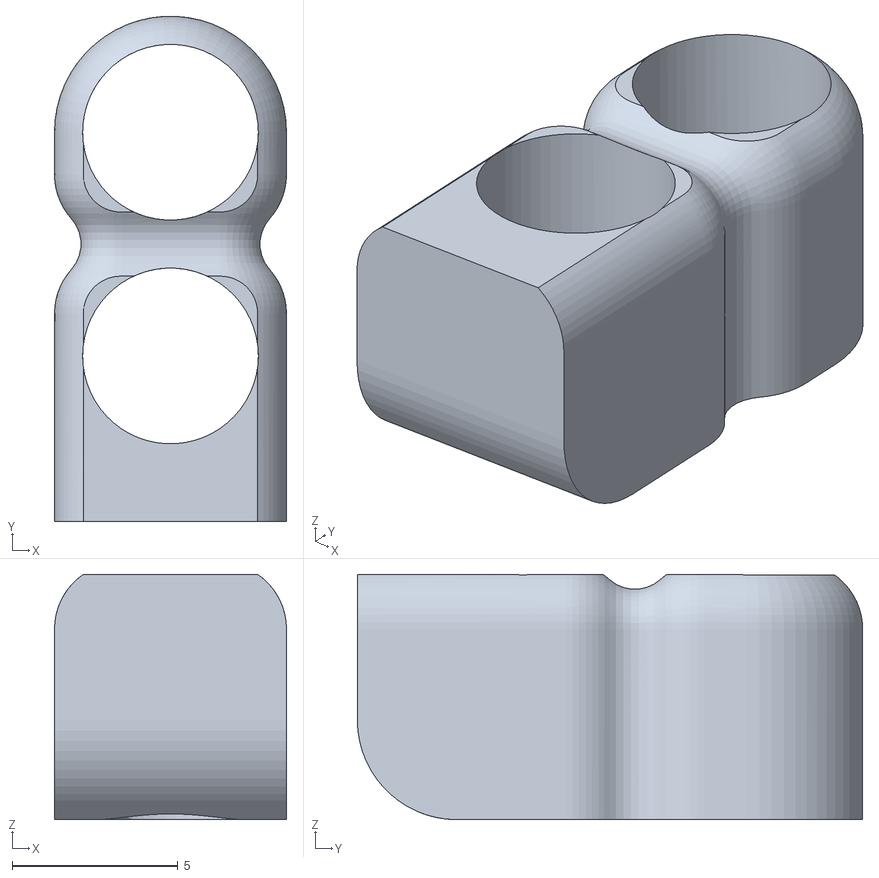
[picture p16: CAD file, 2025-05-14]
3d_model/stl_files/Part Studio - Cover Sensor.stl
7.00 x 15.2 x 7.40

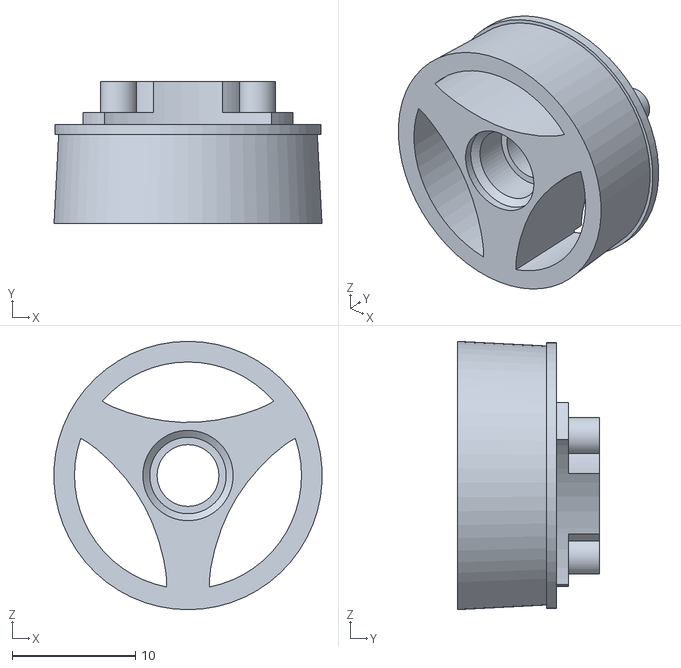
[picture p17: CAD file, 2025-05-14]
3d_model/stl_files/Part Studio - Rueda.stl
21.7 x 11.5 x 21.8

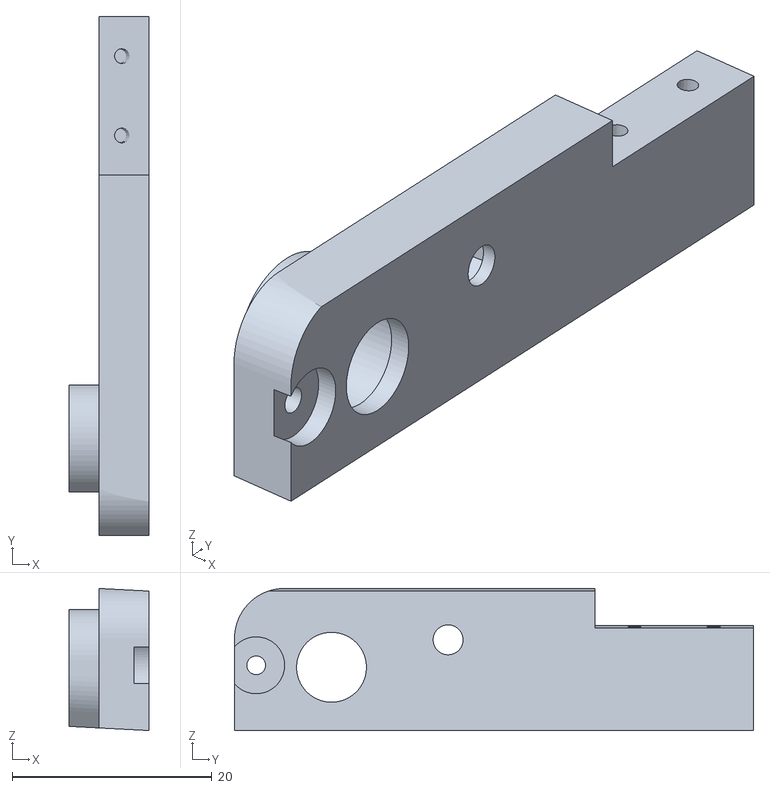
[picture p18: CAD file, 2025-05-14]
3d_model/stl_files/Part Studio - Bracket Motor R.stl
8.00 x 52.0 x 14.2

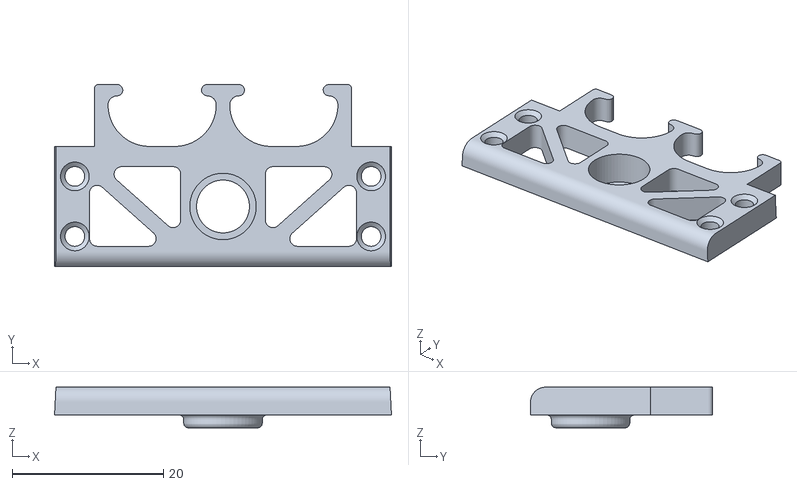
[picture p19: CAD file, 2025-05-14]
3d_model/stl_files/Part Studio - Bracket Ventilador.stl
44.6 x 24.1 x 5.39

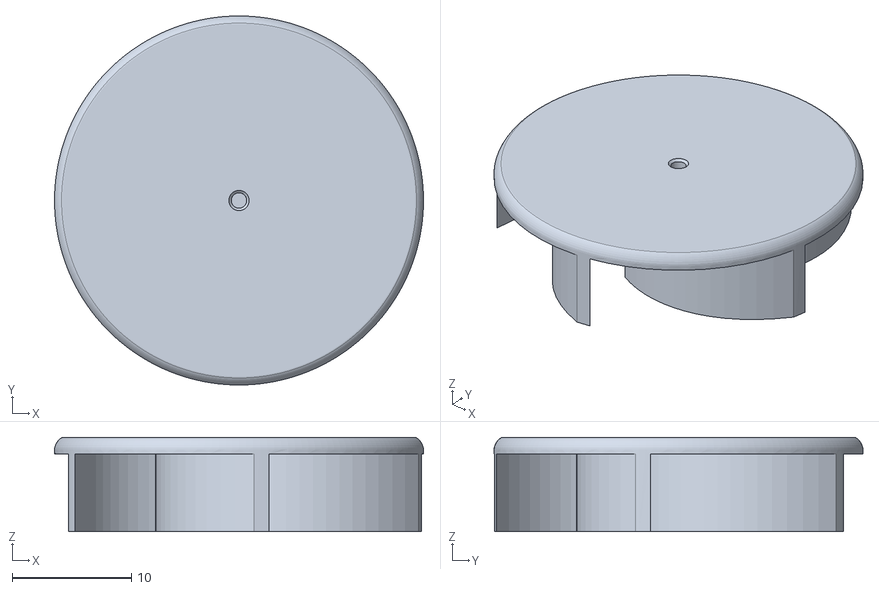
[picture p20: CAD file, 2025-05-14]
3d_model/stl_files/Part Studio - Ventilador_fdm.stl
31.0 x 31.0 x 7.90

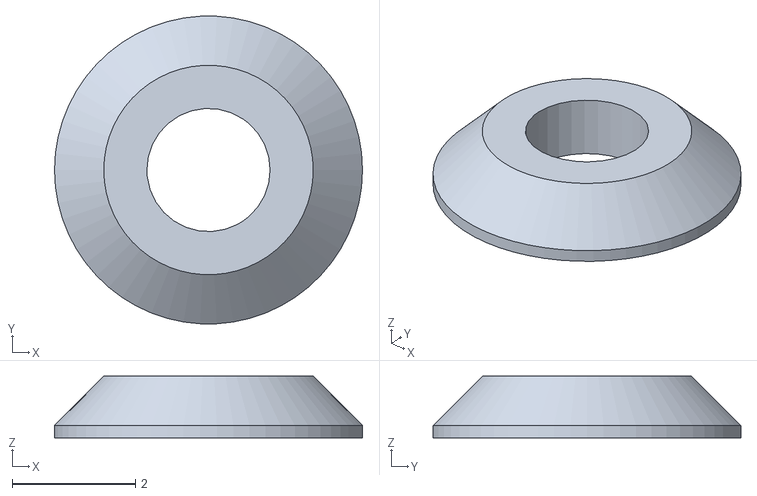
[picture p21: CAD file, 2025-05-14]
3d_model/stl_files/Part Studio - Arandela M2 -editada-.stl
5.00 x 4.99 x 1.00

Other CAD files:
3d_model/stl_files/Part Studio - Bracket Motor L.stl

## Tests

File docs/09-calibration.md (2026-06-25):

# Calibraciones

## Tipos de Calibración

Seleccionables desde el menú CONFIG → CALIBRATION:

| ID | Tipo | Función |
|----|---|---|
| 0 | `CALIBRATE_NONE` | Sin calibración |
| 1 | `CALIBRATE_GYRO_Z` | Offset Z del giroscopio |
| 2 | `CALIBRATE_SIDE_SENSORS_OFFSET` | Offset de sensores laterales |
| 3 | `CALIBRATE_FRONT_SENSORS` | Calibración frontal de pared |
| 4 | `CALIBRATE_FRONT_SENSORS_MIDDLE` | Distancia media frontal |
| 5 | `CALIBRATE_STORE_EEPROM` | Guardar todo en EEPROM |

Archivos: [`calibrations.c`](../source_code/src/calibrations.c), [`calibrations.h`](../source_code/include/calibrations.h).

### Secuencia de Activación

1. Seleccionar el tipo de calibración en el menú.
2. Pulsar MODE para activar → LED verde se enciende.
3. Pulsar DEBUG para ejecutar → LED verde parpadea, delay 2s.
4. La calibración se ejecuta automáticamente.

---

## Calibración del Giroscopio

`lsm6dsr_gyro_z_calibration()` en [`lsm6dsr.c`](../source_code/src/lsm6dsr.c):

1. Robot **quieto** en superficie plana.
2. Toma **200 muestras** del eje Z.
3. Calcula el offset como el promedio de las lecturas.
4. Calibra para **cada full-scale** (1000, 2000, 4000 dps) independientemente.
5. Guarda offsets en EEPROM.

---

## Calibración de Sensores Frontales

`front_sensors_calibration()` en [`sensors.c`](../source_code/src/sensors.c):

1. Posicionar el robot de cara a una pared a **174 mm** (`CELL_DIMENSION − WALL_WIDTH/2`).
2. Toma `SENSOR_FRONT_CALIBRATION_READINGS = 20` muestras.
3. **Umbral raw**: `threshold = Σ(raw_filter) / 20 / (1.5)²` (fórmula corregida con ley 1/d²).
4. **Offset de distancia**: `offset = 174 mm − promedio(distancia_medida)`.
5. Guarda umbrales y offsets en EEPROM.

---

## Calibración Frontal Media

`front_sensors_middle_calibration()` en [`sensors.c`](../source_code/src/sensors.c):

1. Posicionar el robot en el **centro de la celda** (a `MIDDLE_MAZE_DISTANCE = 84 mm` de la pared).
2. Mide la distancia objetivo media y el valor raw equivalente.
3. Estos valores se usan para el control `keep_front_distance()`.

---

## Calibración de Sensores Laterales

`side_sensors_calibration(keep_sensors_on)` en [`sensors.c`](../source_code/src/sensors.c):

1. Posicionar el robot **centrado entre dos paredes**.
2. Toma `SENSOR_SIDE_CALIBRATION_READINGS = 100` muestras.
3. **Umbral raw**: `threshold = Σ(raw_filter) / 100 / (1.5)²`.
4. **Offset de distancia**: `offset = MIDDLE_MAZE_DISTANCE − promedio(distancia_medida)`.
5. Si `keep_sensors_on = false`, desactiva sensores tras calibrar.
6. Guarda en EEPROM.

Esta calibración se ejecuta automáticamente al iniciar:
- `floodfill_start_explore()` — exploración
- `floodfill_start_run()` — speed run

---

## Persistencia en EEPROM

Los datos de calibración se almacenan en el sector flash 11 con checksum para integridad. Ver [EEPROM](11-eeprom.md).

Al arrancar, `eeprom_load()` carga:
- `sensors_distance_offset[4]` — offsets de distancia
- `sensors_raw_wall_detection_threshold[4]` — umbrales raw
- `sensors_middle_target_distance[4]` — distancias medias objetivo
- `offset_z[3]` — offsets del giroscopio por full-scale

Los offsets se imprimen por puerto serie para verificación.

---

## Procedimiento de Calibración Completo

Para una calibración completa del robot:

1. **Giroscopio**: Robot quieto en superficie plana → `CALIBRATE_GYRO_Z` → `CALIBRATE_STORE_EEPROM`
2. **Sensores frontales**: Robot de cara a pared a 174mm → `CALIBRATE_FRONT_SENSORS` → `CALIBRATE_STORE_EEPROM`
3. **Sensores frontales medio**: Robot en centro de celda → `CALIBRATE_FRONT_SENSORS_MIDDLE` → `CALIBRATE_STORE_EEPROM`
4. **Sensores laterales**: Robot centrado entre dos paredes → `CALIBRATE_SIDE_SENSORS_OFFSET` → `CALIBRATE_STORE_EEPROM`

También disponible: `calibrate_manual_distances()` — Al pulsar DEBUG, imprime los valores raw filter de los 4 sensores por puerto serie para verificación manual.

---

*Documento generado el 2026-06-12. Ver también [Sensores](03-sensors.md), [EEPROM](11-eeprom.md), [Encoders y Giroscopio](12-encoders-gyro.md).*

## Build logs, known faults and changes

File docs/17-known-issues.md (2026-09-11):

# Problemas Conocidos

> **Fecha de análisis**: 2026-06-11
> **Última actualización**: 2026-08-25
> **Total**: 64 issues — 10 críticos, 24 moderados, 30 leves

> **Última revisión**: 2026-08-25 (commits `aa1e633`..`2bbbe13`)
> **Issues nuevos**: 17 (HW-01..HW-05, SW-01..SW-03, SP-01..SP-09)
> **Issues corregidos**: 0
> **Issues actualizados**: 0

---

## Correcciones Recientes ✅

| ID | Fecha | Descripción |
|----|---|---|
| SS-01 | 2026-06-11 | Desbordamiento de tabla LUT — añadido bounds checking |
| SS-02 | 2026-06-11 | Análisis de timing: margen 97x, fallo improbable |
| SS-03 | 2026-06-11 | Filtro mediana N=3 + EMA adaptativo (α=0.2/0.6, umbral 10mm) |
| SS-07 | 2026-06-11 | Threshold raw corregido con ley 1/d² (factor 1.5× distancia) |
| SS-15 | 2026-06-11 | Checksum aditivo (complemento a 2) en EEPROM + warning_eeprom |

---

## 🔴 Críticos (10 issues)

### Floodfill

#### FF-01 — Estado insuficiente en el BFS para modo TIME_BASED

<table>
<tr><td><strong>Archivos</strong></td><td><a href="../source_code/src/floodfill.c#L340"><code>floodfill.c:340</code></a></td></tr>
<tr><td><strong>Descripción</strong></td><td>El floodfill almacena un único <code>float</code> por celda. En TIME_BASED, el coste de transición depende del estado (dirección + count). Un camino con tiempo ligeramente superior pero mejor dirección se descarta.</td></tr>
<tr><td><strong>Impacto</strong></td><td><strong>Alto</strong> — puede no encontrar la ruta óptima global.</td></tr>
<tr><td><strong>Mitigación</strong></td><td>Condición <code>&gt;=</code> permite caminos con mismo tiempo pero distinto estado.</td></tr>
<tr><td><strong>Solución</strong></td><td>Ampliar estado a <code>floodfill[celda][direccion]</code> o usar A*.</td></tr>
</table>

#### FF-02 — Desbordamiento de la cola de prioridad ✅ CORREGIDO

<table>
<tr><td><strong>Archivos</strong></td><td><a href="../source_code/include/floodfill.h#L64-L68"><code>floodfill.h:64-68</code></a>, <a href="../source_code/src/floodfill.c#L358-L387"><code>floodfill.c:358-387</code></a></td></tr>
<tr><td><strong>Descripción</strong></td><td>La cola tenía capacidad fija de <code>MAZE_CELLS</code> (256 slots) con <code>head</code>/<code>tail</code> acumulativos. Con la relajación <code>&gt;=</code> de los modos no-BASIC, un mismo <code>update_floodfill()</code> puede encolar bastante más de 256 veces (medido: TIME hasta ~624; DIAGONAL hasta ~14 000 en exploración de laberinto vacío). El push #257 escribía sobre <code>head</code>/<code>tail</code> (offset 4096) → SIGSEGV o floodfill incompleto.</td></tr>
<tr><td><strong>Impacto</strong></td><td><strong>Alto</strong> — corrupción de memoria y caída del simulador. En robot normalmente no se disparaba porque el laberinto cargado de EEPROM reduce los reencolados, pero era UB latente.</td></tr>
<tr><td><strong>Solución</strong></td><td>Capacidad ampliada a <code>MAZE_CELLS × 8</code> (2048 slots, 32 KB) mediante <code>CELLS_QUEUE_CAPACITY</code> y guardas de capacidad en <code>queue_push()</code>/<code>queue_pop()</code>. Se conserva la condición <code>&gt;=</code> (necesaria para estados con distinta orientación en diagonales encadenadas). TIME queda con ~3× de margen; DIAGONAL puede saturar la cola en exploración de laberinto vacío, pero la guarda evita la corrupción y el floodfill sigue siendo completo.</td></tr>
</table>

#### FF-03 — Penalización de giro ausente en transición ortogonal→ortogonal

<table>
<tr><td><strong>Archivos</strong></td><td><a href="../source_code/src/floodfill.c#L515-L520"><code>floodfill.c:515-520</code></a></td></tr>
<tr><td><strong>Descripción</strong></td><td>El caso <code>from_orthogonal &amp;&amp; to_orthogonal</code> no verifica si la dirección cambió.</td></tr>
<tr><td><strong>Impacto</strong></td><td>Bajo en práctica (cubierto por otros casos del switch).</td></tr>
</table>

### Sensores

#### SS-01 — Desbordamiento de tabla LUT ✅ CORREGIDO

<table>
<tr><td><strong>Solución</strong></td><td>Añadido bounds checking: <code>if (ln_index &gt;= LOG_LINEARIZATION_TABLE_SIZE) ln_index = LOG_LINEARIZATION_TABLE_SIZE − 1</code>.</td></tr>
</table>

#### SS-02 — Pérdida de conversiones ADC ✅ CORREGIDO

<table>
<tr><td><strong>Solución</strong></td><td>Análisis de timing confirmó margen 97x. Sin riesgo real.</td></tr>
</table>

#### SS-03 — Sin filtrado de lecturas ADC ✅ CORREGIDO

<table>
<tr><td><strong>Solución</strong></td><td>Añadido: mediana N=3 + EMA adaptativo.</td></tr>
</table>

### Movimiento

#### MV-01 — PID sin anti-windup (6 integradores)

<table>
<tr><td><strong>Archivos</strong></td><td><a href="../source_code/src/control.c#L392-L451"><code>control.c:392-451</code></a></td></tr>
<tr><td><strong>Descripción</strong></td><td>Los 6 integradores acumulan error sin clamping. Tras saturación, overshoot masivo.</td></tr>
<tr><td><strong>Impacto</strong></td><td><strong>Alto</strong> — inestabilidad severa.</td></tr>
<tr><td><strong>Solución</strong></td><td>Implementar clamping condicional (back-calculation o conditional integration).</td></tr>
</table>

#### MV-02 — `move_inplace_turn()` siempre gira a la izquierda

<table>
<tr><td><strong>Archivos</strong></td><td><a href="../source_code/src/move.c#L126-L143"><code>move.c:126-143</code></a></td></tr>
<tr><td><strong>Descripción</strong></td><td>MOVE_BACK, MOVE_BACK_WALL y MOVE_BACK_STOP tienen <code>sign = −1</code> fijo.</td></tr>
<tr><td><strong>Impacto</strong></td><td>Medio-Alto — desviación sistemática en exploración.</td></tr>
</table>

#### MV-03 — `lsm6dsr_read_gyro_z_raw()` depende de auto-incremento SPI no verificado

<table>
<tr><td><strong>Archivos</strong></td><td><a href="../source_code/src/lsm6dsr.c#L66-L73"><code>lsm6dsr.c:66-73</code></a></td></tr>
<tr><td><strong>Descripción</strong></td><td>Asume que IF_INC está habilitado para leer ZL+ZH consecutivos.</td></tr>
<tr><td><strong>Impacto</strong></td><td>Medio — datos incorrectos si IF_INC no está configurado.</td></tr>
</table>

#### MV-04 — `platform_write()` y `platform_read()` ignoran parámetro `len`

<table>
<tr><td><strong>Archivos</strong></td><td><a href="../source_code/src/lsm6dsr.c#L48-L59"><code>lsm6dsr.c:48-59</code></a></td></tr>
<tr><td><strong>Descripción</strong></td><td>Solo transfieren 1 byte independientemente del parámetro <code>len</code>.</td></tr>
<tr><td><strong>Impacto</strong></td><td>Medio — frágil ante cambios de la librería LSM6DSR.</td></tr>
</table>

---

## 🟡 Moderados (24 issues)

### Floodfill

#### FF-04 — `total_time` incorrecto en tabla de pesos

<table>
<tr><td><strong>Descripción</strong></td><td><code>total_time</code> incorrecto en tabla de pesos (primera celda contada 2×).</td></tr>
<tr><td><strong>Impacto</strong></td><td>Bajo.</td></tr>
</table>

#### FF-05 — Índice incorrecto en `mmsim_get_estimated_time()`

<table>
<tr><td><strong>Descripción</strong></td><td><code>mmsim_get_estimated_time()</code> usa índice incorrecto (off-by-one).</td></tr>
<tr><td><strong>Impacto</strong></td><td>Medio.</td></tr>
</table>

#### FF-06 — Modelo de penalización de giro inexacto

<table>
<tr><td><strong>Descripción</strong></td><td>Modelo de penalización de giro inexacto (asume deceleración completa).</td></tr>
<tr><td><strong>Impacto</strong></td><td>Medio.</td></tr>
</table>

#### FF-07 — Orientación inicial no considerada al planificar

<table>
<tr><td><strong>Descripción</strong></td><td>Floodfill no considera orientación inicial del robot al planificar.</td></tr>
<tr><td><strong>Impacto</strong></td><td>Medio.</td></tr>
</table>

### Sensores

#### SS-04 — Fórmula con posible división por ~0

<table>
<tr><td><strong>Descripción</strong></td><td>Fórmula con posible división por ~0.</td></tr>
<tr><td><strong>Estado</strong></td><td>NO APLICA.</td></tr>
</table>

#### SS-05 — Parámetro c negativo (mitigado)

<table>
<tr><td><strong>Descripción</strong></td><td>Parámetro c negativo (mitigado).</td></tr>
<tr><td><strong>Estado</strong></td><td>NO APLICA.</td></tr>
</table>

#### SS-06 — Filtro EMA sustituido por adaptativo

<table>
<tr><td><strong>Descripción</strong></td><td>Filtro EMA sustituido por adaptativo en SS-03.</td></tr>
<tr><td><strong>Estado</strong></td><td>NO APLICA.</td></tr>
</table>

#### SS-07 — Umbral raw corregido con ley 1/d² ✅ CORREGIDO

<table>
<tr><td><strong>Descripción</strong></td><td>Umbral raw corregido con ley 1/d² (factor 1.5× distancia).</td></tr>
</table>

#### SS-08 — Crosstalk óptico potencial

<table>
<tr><td><strong>Descripción</strong></td><td>Crosstalk óptico potencial.</td></tr>
<tr><td><strong>Estado</strong></td><td>NO APLICA.</td></tr>
</table>

#### SS-09 — Umbrales cableados en `get_side_sensors_error()`

<table>
<tr><td><strong>Descripción</strong></td><td>Umbrales cableados en <code>get_side_sensors_error()</code>.</td></tr>
<tr><td><strong>Estado</strong></td><td>NO APLICA.</td></tr>
</table>

#### SS-10 — Fórmula no validada contra datasheet

<table>
<tr><td><strong>Descripción</strong></td><td>Fórmula no validada contra datasheet (validada empíricamente).</td></tr>
<tr><td><strong>Estado</strong></td><td>NO APLICA.</td></tr>
</table>

#### SS-15 — Sin validación de datos EEPROM ✅ CORREGIDO

<table>
<tr><td><strong>Descripción</strong></td><td>Sin validación de datos EEPROM. Corregido con checksum aditivo (complemento a 2) + <code>warning_eeprom</code>.</td></tr>
</table>

### Movimiento

#### MV-05 — Distancia de frenada usa velocidad ideal

<table>
<tr><td><strong>Descripción</strong></td><td>Distancia de frenada usa velocidad ideal, no real.</td></tr>
<tr><td><strong>Impacto</strong></td><td>Medio.</td></tr>
</table>

#### MV-06 — Filtros independientes en velocidad angular

<table>
<tr><td><strong>Descripción</strong></td><td>Velocidad angular con filtros independientes (desfase entre canales).</td></tr>
<tr><td><strong>Impacto</strong></td><td>Bajo-Medio.</td></tr>
</table>

#### MV-07 — PI con 4 decimales

<table>
<tr><td><strong>Descripción</strong></td><td>PI con 4 decimales (error 0.003%).</td></tr>
<tr><td><strong>Impacto</strong></td><td>Bajo.</td></tr>
</table>

#### MV-08 — Fórmulas de `move_inplace_turn()` no cinemáticamente exactas

<table>
<tr><td><strong>Descripción</strong></td><td>Fórmulas <code>move_inplace_turn()</code> no cinemáticamente exactas.</td></tr>
<tr><td><strong>Impacto</strong></td><td>Medio.</td></tr>
</table>

#### MV-09 — Degradación de giro solo hacia abajo

<table>
<tr><td><strong>Descripción</strong></td><td>Degradación de giro solo hacia abajo.</td></tr>
<tr><td><strong>Impacto</strong></td><td>Medio.</td></tr>
</table>

#### MV-10 — Posible inconsistencia de signos en control angular

<table>
<tr><td><strong>Descripción</strong></td><td>Posible inconsistencia de signos en control angular.</td></tr>
<tr><td><strong>Impacto</strong></td><td>Alto potencial.</td></tr>
</table>

#### MV-11 — `move_straight()` negativo no comprueba wall loss

<table>
<tr><td><strong>Descripción</strong></td><td><code>move_straight()</code> negativo no comprueba wall loss.</td></tr>
<tr><td><strong>Impacto</strong></td><td>Bajo.</td></tr>
</table>

### Hardware

#### HW-01 — Esquemático y PCB desincronizados

<table>
<tr><td><strong>Archivos</strong></td><td><code>pcb_files/kicad_project/ZoroBot3.kicad_sch</code>, <code>pcb_files/kicad_project/ZoroBot3.kicad_pcb</code></td></tr>
<tr><td><strong>Descripción</strong></td><td>El commit <code>ced009d</code> añade la SRAM 23AA04M al esquemático (SRAM1 + RRAM1 + CSRAM1 + net <code>NSS_SRAM</code>) y elimina los amplificadores de corriente AD8418, pero el PCB no se ha actualizado: la SRAM no está colocada y los footprints <code>AD8418AWBZ_1/_2</code> siguen presentes. El diff del PCB en ese commit es solo migración de formato KiCad 8→10 (198 footprints idénticos).</td></tr>
<tr><td><strong>Impacto</strong></td><td><strong>Medio-Alto</strong> — fabricar la placa en este estado produciría un PCB sin SRAM y con amplificadores sin función; riesgo de olvido si no se sincroniza antes de fabricar.</td></tr>
<tr><td><strong>Mitigación</strong></td><td>Ninguna — el desfase es silencioso hasta exportar gerbers.</td></tr>
<tr><td><strong>Solución</strong></td><td>Ejecutar <em>Update PCB from Schematic</em> y recolocar/rutear las piezas nuevas y huérfanas antes de la próxima fabricación.</td></tr>
</table>

#### HW-02 — Lectura de corriente sin amplificador front-end

<table>
<tr><td><strong>Archivos</strong></td><td><code>pcb_files/kicad_project/ZoroBot3.kicad_sch</code> (nets <code>CURR_SEN_MI</code>/<code>CURR_SEN_MD</code>)</td></tr>
<tr><td><strong>Descripción</strong></td><td>El commit <code>ced009d</code> anunciaba "añadir lectura de corriente" pero elimina los amplificadores AD8418 y los shunts (<code>SHUNT_MI</code>/<code>SHUNT_MD</code>). Los canales ADC CH14/CH15 (PC4/PC5) quedan conectados sin shunt ni etapa de ganancia, por lo que no miden corriente utilizable.</td></tr>
<tr><td><strong>Impacto</strong></td><td><strong>Medio</strong> — la lectura de corriente de motores queda inoperativa; los canales ADC quedan sin señal útil.</td></tr>
<tr><td><strong>Mitigación</strong></td><td>Ninguna — el firmware no usa estos canales actualmente.</td></tr>
<tr><td><strong>Solución</strong></td><td>Rediseñar el front-end (p. ej. reinsertar AD8418 con shunt, o un amplificador de nueva generación) o eliminar los canales y su documentación.</td></tr>
</table>

#### HW-03 — Diodo de protección del ventilador de succión ausente

<table>
<tr><td><strong>Archivos</strong></td><td><code>pcb_files/kicad_project/ZoroBot3.kicad_sch</code>, <code>ZoroBot3.kicad_pro</code></td></tr>
<tr><td><strong>Descripción</strong></td><td>El commit <code>ced009d</code> menciona un "diodo en succión" pero ningún fichero guardado contiene ese diodo: <code>D14</code> solo existe como designador fantasma en <code>used_designators</code> del proyecto KiCad. El ventilador queda sin diodo de libre circulación/protección.</td></tr>
<tr><td><strong>Impacto</strong></td><td><strong>Medio</strong> — picos de tensión inducidos por el motor del ventilador pueden dañar el MOSFET de control (Q1).</td></tr>
<tr><td><strong>Mitigación</strong></td><td>Ninguna en el diseño actual.</td></tr>
<tr><td><strong>Solución</strong></td><td>Añadir el diodo al esquemático (en paralelo con el ventilador, cátodo a positivo) y propagar a PCB/BOM.</td></tr>
</table>

### Scripts Python

#### SP-01 — Dependencias de los scripts sin declarar

<table>
<tr><td><strong>Archivos</strong></td><td><code>scripts/turn-profiles/*.py</code>, <code>scripts/turn-profiles/*.ipynb</code>, <code>scripts/sensors-profiles/sensors-profiles.ipynb</code></td></tr>
<tr><td><strong>Descripción</strong></td><td>Los scripts importan numpy, matplotlib y pandas (y <code>scipy.optimize</code> en sensors-profiles) sin que exista ninguna declaración de dependencias en el repo: no hay <code>requirements.txt</code> ni <code>pyproject.toml</code> en la raíz ni en <code>scripts/</code> (los únicos requirements son de docs y solo contienen mkdocs). Un entorno limpio falla con <code>ModuleNotFoundError</code> y no queda registro del contrato de runtime.</td></tr>
<tr><td><strong>Impacto</strong></td><td><strong>Medio</strong> — los scripts no son reproducibles en una máquina nueva.</td></tr>
<tr><td><strong>Solución</strong></td><td>Añadir un <code>requirements.txt</code> (numpy, pandas, matplotlib, scipy) en <code>scripts/</code> o en la raíz y referenciarlo en los README de los scripts.</td></tr>
</table>

#### SP-02 — Imports dependientes del directorio de trabajo

<table>
<tr><td><strong>Archivos</strong></td><td><code>scripts/turn-profiles/aux/verify_profiles.py:9</code>, <code>aux/deep_analysis.py:7</code>, <code>aux/analyze_all_pairs.py:10</code>, <code>aux/test_new_exit.py:14</code>, <code>turn-profiles.ipynb</code> (celda 2)</td></tr>
<tr><td><strong>Descripción</strong></td><td>Los cuatro scripts auxiliares hacen <code>sys.path.insert(0, '.')</code> e importan la biblioteca principal: solo funciona si el CWD es exactamente <code>scripts/turn-profiles/</code>. El notebook tiene la misma dependencia oculta (importa el módulo sin manipular el path). Desde cualquier otro directorio falla con <code>ModuleNotFoundError</code> sin diagnóstico útil.</td></tr>
<tr><td><strong>Impacto</strong></td><td><strong>Medio</strong> — scripts frágiles ante la forma de invocación.</td></tr>
<tr><td><strong>Solución</strong></td><td>Derivar la ruta del módulo desde <code>__file__</code> (p. ej. <code>sys.path.insert(0, str(Path(__file__).resolve().parent.parent))</code>) o empaquetar el módulo; documentar el requisito de CWD en el notebook.</td></tr>
</table>

---

## 🟢 Leves (30 issues)

### Floodfill

#### FF-08 — Código inalcanzable tras `return` en switches

<table>
<tr><td><strong>Descripción</strong></td><td>Código inalcanzable tras <code>return</code> en switches.</td></tr>
</table>

#### FF-09 — `#pragma GCC diagnostic` ignora `-Wswitch`

<table>
<tr><td><strong>Descripción</strong></td><td><code>#pragma GCC diagnostic</code> ignora <code>-Wswitch</code>.</td></tr>
</table>

#### FF-10 — `time_penalty` retorna 0 si `init_speed >= speed`

<table>
<tr><td><strong>Descripción</strong></td><td><code>time_penalty</code> retorna 0 si <code>init_speed &gt;= speed</code>.</td></tr>
</table>

#### FF-11 — `get_direction_value()` devuelve 0 para diagonales

<table>
<tr><td><strong>Descripción</strong></td><td><code>get_direction_value()</code> devuelve 0 para diagonales.</td></tr>
</table>

#### FF-12 — Sesgo direccional en `floodfill_run()`

<table>
<tr><td><strong>Descripción</strong></td><td>Sesgo direccional en <code>floodfill_run()</code> (NORTH siempre gana empates).</td></tr>
</table>

#### FF-13 — `cells_to_max_speed` puede exceder el buffer de pesos

<table>
<tr><td><strong>Descripción</strong></td><td><code>cells_to_max_speed</code> puede exceder <code>FLOODFILL_MAX_WEIGHTS_COUNT</code>.</td></tr>
</table>

### Sensores

#### SS-11 — `update_side_sensors_leds()` con código repetitivo

<table>
<tr><td><strong>Descripción</strong></td><td><code>update_side_sensors_leds()</code> con código repetitivo.</td></tr>
<tr><td><strong>Estado</strong></td><td>NO APLICA.</td></tr>
</table>

#### SS-12 — `all_sensors_take_values()` bucle infinito (debug)

<table>
<tr><td><strong>Descripción</strong></td><td><code>all_sensors_take_values()</code> bucle infinito (debug).</td></tr>
<tr><td><strong>Estado</strong></td><td>NO APLICA.</td></tr>
</table>

#### SS-13 — Flag `sensors_taking_values` nunca a false

<table>
<tr><td><strong>Descripción</strong></td><td>Flag <code>sensors_taking_values</code> nunca a false.</td></tr>
<tr><td><strong>Estado</strong></td><td>NO APLICA.</td></tr>
</table>

#### SS-14 — División entera en calibración

<table>
<tr><td><strong>Descripción</strong></td><td>División entera en calibración (error ±1 sobre ~2000).</td></tr>
<tr><td><strong>Estado</strong></td><td>NO APLICA.</td></tr>
</table>

### Movimiento

#### MV-12 — `avg_micrometers`/`avg_millimeters` nunca actualizadas

<table>
<tr><td><strong>Descripción</strong></td><td><code>avg_micrometers</code>/<code>avg_millimeters</code> nunca actualizadas (código muerto).</td></tr>
</table>

#### MV-13 — `volatile` innecesario en variables de control PID

<table>
<tr><td><strong>Descripción</strong></td><td><code>volatile</code> innecesario en variables de control PID.</td></tr>
</table>

#### MV-14 — Expresión redundante `true &&` en `move_arc_turn()`

<table>
<tr><td><strong>Descripción</strong></td><td>Expresión redundante <code>true &amp;&amp;</code> en <code>move_arc_turn()</code>.</td></tr>
</table>

#### MV-15 — Número mágico `1.75f` en `move_back()`

<table>
<tr><td><strong>Descripción</strong></td><td>Número mágico <code>1.75f</code> en <code>move_back()</code>.</td></tr>
</table>

#### MV-16 — Parámetros `start`/`end` negativos sin validación de rango

<table>
<tr><td><strong>Descripción</strong></td><td>Parámetros <code>start</code>/<code>end</code> negativos sin validación de rango.</td></tr>
</table>

#### MV-17 — `check_wall_loss_correction()` solo paredes laterales

<table>
<tr><td><strong>Descripción</strong></td><td><code>check_wall_loss_correction()</code> solo paredes laterales.</td></tr>
</table>

#### MV-18 — Frecuencia acoplada rígidamente a SysTick = 16 kHz

<table>
<tr><td><strong>Descripción</strong></td><td>Frecuencia acoplada rígidamente a SysTick = 16 kHz.</td></tr>
</table>

#### MV-19 — Wrap-around de timer de encoders (verificado correcto ✅)

<table>
<tr><td><strong>Descripción</strong></td><td>Wrap-around de timer de encoders (verificado correcto ✅).</td></tr>
</table>

### Hardware

#### HW-04 — BOM desactualizado

<table>
<tr><td><strong>Archivos</strong></td><td><code>pcb_files/gerbers/bom.csv</code> (+ <code>designators.csv</code>, <code>positions.csv</code>)</td></tr>
<tr><td><strong>Descripción</strong></td><td>El BOM generado es anterior al rango revisado: lista los AD8418 eliminados del esquemático y no incluye SRAM1/RRAM1/CSRAM1 (23AA04M, 10 kΩ, 100 nF).</td></tr>
<tr><td><strong>Impacto</strong></td><td>Bajo — pedido de componentes incorrecto si se usa el BOM sin regenerar.</td></tr>
<tr><td><strong>Solución</strong></td><td>Regenerar el BOM desde el esquemático actual (export BOM de KiCad) cuando el diseño se estabilice.</td></tr>
</table>

#### HW-05 — SRAM sin soporte en firmware

<table>
<tr><td><strong>Archivos</strong></td><td><code>source_code/</code> (sin driver); <code>pcb_files/kicad_project/ZoroBot3.kicad_sch</code> (SRAM1)</td></tr>
<tr><td><strong>Descripción</strong></td><td>La SRAM 23AA04M-I/ST (4 Mbit) está conectada al bus SPI3 compartido con CS dedicado en PB12 (pull-up 10 kΩ), pero no existe driver ni inicialización en el firmware. PB12 está libre en el código actual.</td></tr>
<tr><td><strong>Impacto</strong></td><td>Bajo — la SRAM no es utilizable hasta añadir el driver.</td></tr>
<tr><td><strong>Solución</strong></td><td>Implementar driver SPI (modo byte) con CS en PB12 e integrar el uso previsto de la SRAM.</td></tr>
</table>

### Arquitectura Software

#### SW-01 — Comentarios de `setup_spi()` incorrectos

<table>
<tr><td><strong>Archivos</strong></td><td><a href="../source_code/src/setup.c#L328-L332"><code>setup.c:328-332</code></a></td></tr>
<tr><td><strong>Descripción</strong></td><td>El comentario documenta CPHA 0 ("los datos de entrada se capturan en el flanco ascendente") pero el código usa <code>SPI_CR1_CPHA_CLK_TRANSITION_1</code> (CPHA 1, captura en el segundo flanco). Además los comentarios de frecuencia mezclan PCLK1 = 36 MHz con 84 MHz para el cálculo del divisor SPI.</td></tr>
<tr><td><strong>Impacto</strong></td><td>Bajo — riesgo de configuraciones erróneas en cambios futuros guiados por el comentario.</td></tr>
<tr><td><strong>Solución</strong></td><td>Corregir el comentario al valor real del registro (CPHA 1) y unificar las frecuencias de reloj citadas.</td></tr>
</table>

#### SW-02 — `setup_spi_low_speed()` código muerto

<table>
<tr><td><strong>Archivos</strong></td><td><a href="../source_code/src/setup.c#L375-L378"><code>setup.c:375-378</code></a></td></tr>
<tr><td><strong>Descripción</strong></td><td>La función <code>setup_spi_low_speed()</code> está definida pero nunca se llama en todo el firmware.</td></tr>
<tr><td><strong>Impacto</strong></td><td>Bajo — mantenibilidad.</td></tr>
<tr><td><strong>Solución</strong></td><td>Eliminarla o usarla donde corresponda.</td></tr>
</table>

#### SW-03 — openocd_reset.cfg referencia STM32F401

<table>
<tr><td><strong>Archivos</strong></td><td><a href="../source_code/openocd_reset.cfg"><code>openocd_reset.cfg</code></a></td></tr>
<tr><td><strong>Descripción</strong></td><td>El comentario sobre flash de banco único menciona "STM32F401"; el target real es un STM32F405 (también de banco único, por lo que el comportamiento descrito es correcto).</td></tr>
<tr><td><strong>Impacto</strong></td><td>Bajo — confusión al leer la configuración.</td></tr>
<tr><td><strong>Solución</strong></td><td>Cambiar el comentario a STM32F405.</td></tr>
</table>

### Scripts Python

#### SP-03 — `ValueError` sin mensaje en perfiles slalom infeasibles

<table>
<tr><td><strong>Archivos</strong></td><td><code>scripts/turn-profiles/micromouse_sinusoidal_turn_profiles_aux.py:299</code>, <code>aux/test_new_exit.py:199-200</code></td></tr>
<tr><td><strong>Descripción</strong></td><td>Cuando un perfil slalom es infeasible, se lanza <code>raise ValueError</code> sin mensaje. El capturador en <code>test_new_exit.py</code> imprime <code>turn_shift failed (lines parallel) - {e}</code> con mensaje vacío, atribuyendo la causa a líneas paralelas cuando en realidad es la comprobación de velocidad angular de la transición.</td></tr>
<tr><td><strong>Impacto</strong></td><td>Bajo — diagnóstico engañoso.</td></tr>
<tr><td><strong>Solución</strong></td><td><code>raise ValueError(f'transition-only angular velocity {max_angular_velocity_transition:.3f} &lt; required {max_angular_velocity:.3f}')</code>.</td></tr>
</table>

#### SP-04 — `except Exception` genérico oculta bugs como fallos de estrategia

<table>
<tr><td><strong>Archivos</strong></td><td><code>scripts/turn-profiles/aux/test_new_exit.py:232</code></td></tr>
<tr><td><strong>Descripción</strong></td><td>El <code>except Exception as e</code> exterior del bucle de estrategias imprime <code>ERROR - {e}</code> y hace <code>continue</code>. Cualquier error de programación real (KeyError, NaN, typo) dentro del try se reporta como fallo de la estrategia de shift, sin traceback ni re-raise. El <code>except ValueError</code> interno (líneas 194-201) ya cubre el caso esperado.</td></tr>
<tr><td><strong>Impacto</strong></td><td>Bajo — bugs reales se ocultan como resultados legítimos del análisis.</td></tr>
<tr><td><strong>Solución</strong></td><td>Eliminar el <code>except Exception</code> exterior, o re-lanzar tras imprimir con <code>traceback.print_exc()</code>.</td></tr>
</table>

#### SP-05 — Código muerto y comentado sin explicación

<table>
<tr><td><strong>Archivos</strong></td><td><code>scripts/turn-profiles/aux/test_new_exit.py:82</code>, <code>micromouse_sinusoidal_turn_profiles_aux.py:288</code></td></tr>
<tr><td><strong>Descripción</strong></td><td>Línea muerta errónea en <code>test_new_exit.py:82</code> (usa la columna <code>y</code> en vez de <code>x</code>, marcada como "wrong, let me recalc", nunca usada — el cálculo correcto sigue en 85-86) y fórmula comentada en la biblioteca (línea 288) sin explicación de por qué se sustituyó.</td></tr>
<tr><td><strong>Impacto</strong></td><td>Bajo — mantenibilidad; la línea errónea induciría a error si se reactivara.</td></tr>
<tr><td><strong>Solución</strong></td><td>Eliminar la línea 82 y el comentario de la 288 (o documentar el motivo de la sustitución).</td></tr>
</table>

#### SP-06 — Encoding corrupto en `verify_profiles.py`

<table>
<tr><td><strong>Archivos</strong></td><td><code>scripts/turn-profiles/aux/verify_profiles.py</code></td></tr>
<tr><td><strong>Descripción</strong></td><td>El archivo contiene 1428 bytes de <code>?</code> literales donde debería haber ✓/✗/═/acentos: "Script de verificaci??n", separadores "????????", y los marcadores pass/fail muestran "???" en ambas ramas. El veredicto del script — su función principal — queda ilegible.</td></tr>
<tr><td><strong>Impacto</strong></td><td>Bajo — el lector debe inferir el resultado de los ratios numéricos.</td></tr>
<tr><td><strong>Solución</strong></td><td>Reescribir los caracteres (✓/✗, ═, verificación) y verificar la codificación UTF-8 al guardar.</td></tr>
</table>

#### SP-07 — Clasificación "PERPENDICULAR" errónea en `analyze_all_pairs.py`

<table>
<tr><td><strong>Archivos</strong></td><td><code>scripts/turn-profiles/aux/analyze_all_pairs.py:297-306</code></td></tr>
<tr><td><strong>Descripción</strong></td><td>Tras normalizar los ángulos a [0, π/2], el código clasifica como perpendiculares los pares con <code>abs(angle_between - π/4) &lt; 0.01</code>. Las líneas perpendiculares difieren π/2 (90°), no π/4: pares a 45° se etiquetan "PERPENDICULAR", alimentando el razonamiento de PART 4 sobre qué pares de giro necesitan tramo recto intermedio.</td></tr>
<tr><td><strong>Impacto</strong></td><td>Bajo — decisiones de diseño basadas en salida incorrecta.</td></tr>
<tr><td><strong>Solución</strong></td><td><code>is_perpendicular = abs(angle_between - π/2) &lt; 0.01</code>.</td></tr>
</table>

#### SP-08 — Notebook de turn-profiles con 3 MB de figuras y títulos con mojibake

<table>
<tr><td><strong>Archivos</strong></td><td><code>scripts/turn-profiles/turn-profiles.ipynb</code> (celdas 7, 9, 11, 13, 15, 17)</td></tr>
<tr><td><strong>Descripción</strong></td><td>42 figuras PNG de 1600×1600 embebidas en el notebook (3.06 MB total) y 36 títulos con la secuencia "Âº" (mojibake del carácter °): p. ej. <code>plot_trajectory(title = "90Âº NORMAL")</code>. El notebook pesa 3.1 MB, renderiza lento y los títulos guardados están corruptos.</td></tr>
<tr><td><strong>Impacto</strong></td><td>Bajo — repo inflado y salida degradada.</td></tr>
<tr><td><strong>Solución</strong></td><td>Reducir a <code>dpi=80-100</code> o guardar figuras en <code>images/</code> y referenciarlas; reemplazar <code>Âº</code> por <code>°</code>.</td></tr>
</table>

#### SP-09 — Structs de calibración solo en stdout, sin artefacto diffable

<table>
<tr><td><strong>Archivos</strong></td><td><code>scripts/sensors-profiles/sensors-profiles.ipynb</code> (celda 8)</td></tr>
<tr><td><strong>Descripción</strong></td><td>Los coeficientes a/b/c que deben aterrizar en <code>sensors.c</code> se emiten solo como salida impresa de la celda 8. No existe artefacto en fichero ni comprobación contra los valores commitados en el firmware: cambiar <code>ACTIVE_DATASETS</code> o los rangos de ajuste modifica silenciosamente los structs emitidos sin dejar rastro diffable.</td></tr>
<tr><td><strong>Impacto</strong></td><td>Bajo — las constantes del firmware pueden derivar del análisis sin detectarse.</td></tr>
<tr><td><strong>Solución</strong></td><td>Hacer que la celda 8 escriba a un fichero (p. ej. <code>generated/sensors_calibration.h</code>) o afirme igualdad con los valores del firmware; añadir nota de orden de ejecución.</td></tr>
</table>

---

## Resumen por Prioridades

| Prioridad | Cantidad | Issues |
|---|:---:|---|
| 🔴 Críticos | 10 | FF-01..03, SS-01..03, MV-01..04 |
| 🟡 Moderados | 24 | FF-04..07, SS-04..10/15, MV-05..11, HW-01..03, SP-01..02 |
| 🟢 Leves | 30 | FF-08..13, SS-11..14, MV-12..19, HW-04..05, SW-01..03, SP-03..09 |
| **TOTAL** | **64** | |

---

*Documento actualizado el 2026-08-25. El registro de issues se mantiene en este mismo documento, con anchors estables (`#xx-NN`) para referencias cruzadas desde el resto de la documentación.*

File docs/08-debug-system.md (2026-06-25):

# Sistema de Debug

## Modos de Debug

11 modos seleccionables desde el menú CONFIG → DEBUG. Archivos: [`debug.c`](../source_code/src/debug.c), [`debug.h`](../source_code/include/debug.h).

### 0. `DEBUG_NONE` — Sin debug
Operación normal.

### 1. `DEBUG_MACROARRAY` — Datos de macroarray
Imprime los datos almacenados en el buffer de macroarray por puerto serie. Útil para analizar datos de control post-carrera.

### 2. `DEBUG_TYPE_SENSORS` — Sensores en vivo
- **Toggle con UP**: alterna entre modo raw y distancias.
- Modo raw: imprime `sensors_on`, `sensors_off`, `raw_filter` para los 4 sensores.
- Modo distancias: imprime distancias en mm, detección de paredes, errores laterales/diagonales/angulares.
- Frecuencia: ~50 ms entre lecturas.

### 3. `DEBUG_ENCODERS` — Encoders
Imprime milímetros del encoder izquierdo y derecho a ~50 ms.

### 4. `DEBUG_GYRO` — Giroscopio
Imprime valor raw, ángulo integrado y velocidad angular del giroscopio Z.

### 5. `DEBUG_FLOODFILL_MAZE` — Maze + Floodfill
Llama a `floodfill_maze_print()` que imprime:
- Laberinto completo con paredes (formato ASCII)
- Valores de floodfill por celda
- Secuencia de movimientos generada
Desactiva el debug tras la impresión.

### 6. `DEBUG_MOTORS_CURRENT` — Corriente de motores
- Activa motores a velocidad 150.
- Imprime valores de encoders.
- Permite medir consumo con los motores en movimiento.

### 7. `DEBUG_TIMETRIAL` — Demo Time Trial
Ejecuta una demo: 2 celdas recto + 3× (1 celda + giro 90° derecha).
Usa la configuración cinemática actual.

### 8. `DEBUG_KEEP_FRONT_DISTANCE` — Demo distancia frontal
- Activa sensores frontales.
- Configura control para mantener distancia a pared frontal.
- Prueba el PID de distancia frontal.

### 9. `DEBUG_GYRO_DEMO` — Demo estabilización giro
Ejecuta `keep_z_angle()` en bucle para probar la estabilización del giroscopio.

### 10. `DEBUG_FAN_DEMO` — Demo ventilador
Activa el ventilador a la velocidad configurada para la cinemática actual.

---

## Salida Serie (USART)

USART3 a 115200 baud:
- **TX**: PC6
- **RX**: PC7
- `printf()` redirigido mediante `_write()` en [`usart.c`](../source_code/src/usart.c).

### Formato de Impresión

```
// Sensores raw
"S1: 1234 S2: 2345 S3: 3456 S4: 0123"

// Sensores distancia
"D1: 180 D2: 175 W: L01 R01 F00 | err: +1.5 dErr: -0.3 aErr: +2"

// Aux analógicos
"BA: 3456 CI: 0123 CD: 2345 BO: 1234"

// Batería
"BA: 8.23V"

// Encoders
"L: 12345 R: 12346"

// Giroscopio
"Z(raw): -123 Z(dps): -4.305 Z(deg): 12.34"
```

---

## LEDs de Información

10 LEDs de información + 1 LED de estado + 1 LED RGB. Ver [Batería y LEDs](13-battery-leds.md) para detalles completos.

Funciones de visualización para debug:
- `update_side_sensors_leds()` — Muestra error de sensores laterales en barra de 8 LEDs.
- `set_leds_front_sensors()` — Muestra estado de sensores frontales.
- `set_info_led()` / `set_info_leds()` / `clear_info_leds()` — Control individual de LEDs.
- `set_RGB_color(r,g,b)` — LED RGB (hasta 1024 niveles por canal).
- `set_RGB_rainbow()` — Ciclo de colores automático.

---

## Macroarray

Sistema de logging para depuración post-carrera ([`macroarray.h`](../source_code/include/macroarray.h)):

```c
#define MACROARRAY_LENGTH 30000
```

- `macroarray_store(data)` — Almacena datos de control durante la carrera.
- `macroarray_print()` — Imprime el buffer completo por USART.
- Activado cuando `race_started` y hay movimiento no nulo.

Los datos almacenados incluyen errores de control, velocidades y PWM para análisis offline.

---

## Zona de Debug en Main

Al final de [`main.c:158-202`](../source_code/src/main.c#L158-L202) hay una **zona de debug temporal** con código comentado para pruebas rápidas:

```c
// LED WARNING     → warning_status_led(125)
// LEDS MENU       → set_leds_wave(125)
// LED RGB         → set_RGB_color(r,g,b) / set_RGB_rainbow()
// MPU             → lsm6dsr_get_gyro_z_*
// VENTILADOR      → set_fan_speed(50)
// MOTORES         → set_motors_speed(20, 20)
// SENSORES        → get_sensor_raw(...)
// AUX ANALÓGICOS  → get_aux_raw(...)
// ENCODERS        → get_encoder_left_millimeters()
```

Esta zona es inalcanzable en operación normal (está después de un `while(1)` infinito), pero sirve como referencia de pruebas unitarias.

---

*Documento generado el 2026-06-12. Ver también [Menú](07-menu-system.md), [Batería y LEDs](13-battery-leds.md), [Arquitectura Software](02-software-architecture.md).*

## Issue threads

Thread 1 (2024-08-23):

Mantener valores de las integrales de los sensores aun sin estar activo su control

robotaleh, 2024-08-23:
### Contexto
Al desactivar el control de los sensores de pared se dejan de aplicar todos sus respectivos errores. Además, después de cada giro, se resetean a cero los valores de las integrales de los sensores.

### Propuesta
1. Resetear los errores integrales de los sensores únicamente al inicio y cuando se realice un giro de 180º (puede que solo con pared trasera)
2. Seguir aplicando la parte integral del error de los sensores durante todo el tiempo. Si no está activo ese control, no se modificará su valor y la parte proporcional pasará a ser 0, pero se seguirá aplicando la parte integral de la misma forma que antes de haberse desactivado ese error.

### Objetivo
Mejorar la estabilidad general de la entrada y salida de los giros, así como los cambios de sentido en 180º al mantener la posible corrección estacionaria anterior al movimiento.

robotaleh, 2024-08-23:
Quedan los cambios aplicados y pendientes de validar la estabilidad en siguientes pruebas.
Un detalle a tener en cuenta es que habíamos añadido un reseteo del error angular antes de los giros debido a un efecto raro que parecía deberse a una acumulación de error. Este reseteo está desactivado por ahora.

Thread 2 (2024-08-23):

Añadir nuevos perfiles de giro "senoidales" no dependientes del tiempo

robotaleh, 2024-08-23:
### Contexto
Por ahora los giros están definidos según unas gráficas diseñadas por Green Yee. Estas gráficas permiten ajustar de forma manual la velocidad de entrada, radio y angulo de giro, aceleración angular y velocidad angular máxima. Con estos datos se ajustan los **tiempos** de aceleración, velocidad angular máxima y deceleración para realizar el giro.

En general el resultado es bastante bueno, pero es posible que se pueda mejorar...

### Propuesta
Migrar los perfiles de giros lineales y dependientes del tiempo a unos sinusoidales y dependientes de la distancia recorrida tomando como base los perfiles de giro de [bulebule](https://github.com/Bulebots/bulebule).

En estos perfiles la velocidad angular máxima se calculará en función de la velocidad lineal y el radio del giro. Además, se definirán *de forma empírica* unas distancias (arcos) de aceleración y deceleración en los cuales se ejecutará la variación senoidal de la aceleración angular en base a un "factor de avance del arco".

### Objetivo
Mejorar la estabilidad y repititibilidad de los giros, además de simplificar la gestión de los perfiles de giro en función del perfil de velocidad. En principio, con este método bastaría con tener un único perfil de giro para cada tipo de curva ya que se adaptaría la velocidad angular de forma dinámica según la lineal.

robotaleh, 2025-05-11:
Añadido en efdf092

Closed 2025-05-11.

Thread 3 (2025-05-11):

Giros a alta velocidad en casillas cercanas al inicio

robotaleh, 2025-05-11:
### Contexto
En la Run, cuando la configuración de velocidad es muy alta es posible que se intenten realizar giros a una velocidad lineal más alta de la que es posible alcanzar antes de llegar a estos.

### Propuesta
Controlar antes de cada giro que la velocidad lineal ideal sea igual a la del giro que se pretende realizar y, en caso contrario, obtener los parámetros del giro que más cerca se encuentre de esa velocidad ideal.

### Objetivo
Evitar que en los primeros giros el robot pierda la referencia respecto al centro de las casillas debido a inconsistencias entre la relación de velocidad lineal y angular.

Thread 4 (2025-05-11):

Asignar PWM de ventilador de succión en función de la batería

robotaleh, 2025-05-11:
### Contexto
Como el ventilador de succión funciona puramente por PWM es muy dependiente de la carga de la LiPo, al contrario de los motores de tracción que tienen un sistema de control en bucle cerrado mediante los encoders.

### Propuesta
Usar el nivel de carga de la batería al iniciar la run/mapeo para determinar el % de PWM que se debe aplicar al ventilador, en función del % definido para el perfil de velocidades seleccionado.

### Objetivo
Mantener lo más constante posible la fuerza de succión del robot entre runs e independizarlo del nivel de batería que tenga.

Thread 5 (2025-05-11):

Añadir código de time-trial como opción del menú

robotaleh, 2025-05-11:
### Contexto
En la [Micromouse Portugese Contest](https://micromouse.utad.pt/index.html) tienen una modalidad de competición llamada [Time Trials](https://micromouse.utad.pt/pages/time_contest_rules.html)

### Propuesta
Añadir por menú un nuevo tipo de competición con los movimientos hardcodeados tanto para laberinto de pruebas 6x6 como para competición 16x16

### Objetivo
Evitar tener que cargar programa para poder hacer pruebas de Time Trial

robotaleh, 2025-05-16:
Aplicado en 7961cbf4cbf37f4b201d4235703bfb8e930fd252

Closed 2025-05-16.

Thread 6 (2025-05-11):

Mejorar y añadir más funciones de debug por menú

robotaleh, 2025-05-11:
### Contexto
A veces es necesario realizar una valoración rápida de ciertos aspectos del robot y se pierde mucho tiempo teniendo que cargar programa para verlo.

### Objetivo
Tener las máximas comprobaciones de hardware posibles mediante el menú de Debug. Actualmente ya se imprimen los sensores y distancias, pero también habría que añadir motores, encoders, giroscopio, ...

### Propuesta
Revisar exhaustivamente el menú actual de Debug para añadir las máximas comprobaciones y debugs posibles, así como mejorar las existentes para hacerlas lo más útiles posible.

20leunam, 2025-09-22:
Quizas se pueda juntar el debug de sensores raw y sensores en mm en un debug.
A mayores habria que añadir un raw del giro o todo lo relacionado con el giro.

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

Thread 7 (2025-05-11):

Modificar las funciones de run para permitir decimales

robotaleh, 2025-05-11:
### Contexto
Las funciones de _run_straight_ y _run_diagonal_ reciben como parámetro la distancia que deben realizar en forma de número entero. Sin embargo, los offsets de los giros están en decimales. Además, el movimiento en diagonal también es decimal, por lo que puede que se estén perdiendo milímetros en el sumatorio.

### Objetivo
Mejorar el sumatorio de distancia en recto teniendo en eucnta los offsets de los giros para ajustar lo mejor posible la posición del robot al final del giro. De esta forma los siguientes movimientos tendrán más posiblidad de éxito al no tener que corregir tanto la posición lateral respecto a la casilla

### Propuesta
Modificar todas las distancias a floats y revisar su sumatorio para asegurar que no se están perdiendo milimetros en trayectos rectos o diagonales largos. También sería interesante contrastar las distancias calculadas con las reales de una forma fiable para comprobar que se calculen correctamente.

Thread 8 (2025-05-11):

Aceleraciones en zonas conocidas del mapeo

robotaleh, 2025-05-11:
### Contexto
Durante el mapeo de un laberinto de 16x16 es muy probable que vuelva a recorrer zonas ya conocidas al encontrarse con caminos sin salida lo cual es una pérdida de tiempo al tener un tiempo límite de 7 a 10 minutos para todos los intentos.

### Objetivo
Recortar tiempo para invertir en las run al realizar aceleraciones suaves y seguras en zonas ya conocidas del laberinto. Inicialmente no se contempla la implementación de diagonales en el mapeo para evitar riesgos innecesarios (quizás se podrían aplicar en caso de tener al menos un camino conocido hasta la meta)

### Propuesta
Mientras se está realizando el mapeo, ir comprobando si las siguientes casillas indicadas por el FloodFill ya han sido visitadas para poder acelerar a través de ellas. En principio solo se contemplarán las casillas consecutivas en la misma dirección para realizar las aceleraciones.

Closed 2025-09-04.

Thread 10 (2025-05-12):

Apagar la succion mas rapido cuando finaliza el mapeo

20leunam, 2025-05-12:
**Contexto**
Cuando llega a la casilla de salida despues de mapear tiene como 5 o 3 seg la succion activa. Lo cual se hace largo entre pruebas.

**Objetivo**
Mejorar la comodidad entre pruebas

**Propuesta**
Bajar el tiempo a 0.5s (?)

Closed 2025-05-16.

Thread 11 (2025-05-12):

Añadir a la demo de giroscopio control de velocidad en 0m/s

20leunam, 2025-05-12:
**Contexto**
En la demo de giroscopio el robot se mantiene centrado si le mueves el suelo pero a veces se va desplazando

**Objetivo**
Si se realiza esto tambien ganara como demo pudiendo empujar el robot o inclinar la plataforma y que no le mueva ni angular ni linealmente

**Propuesta**
añadir control lineal a 0m/s

Closed 2025-05-16.

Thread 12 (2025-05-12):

Añadir control de pared frontal al menu de demos

20leunam, 2025-05-12:
**Contexto**
Tenemos dos demos, giro y succión. proponemos añadir alguna mas

**Objetivo**
Que el robot pueda seguir una pared frontal a una pared con un PID manteniendo siempre una distancia objetivo

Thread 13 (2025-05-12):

Añadir control de 0m/s a la demo de succion

20leunam, 2025-05-12:
**Contexto**
La demo de succion el robot se puede mover y puede probocar caidas en un cristal si te despistas

**Objetivo**
Poner control de velocidad lineal por encoders a velocidad 0m/s para que se mantenga quieto en el sitio y no preocuparse al darle la vuelta al robot

**Propuesta**
añadir control lineal a 0m/s

Closed 2025-05-16.

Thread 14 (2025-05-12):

Añadir un Time Trial chiquito a las demos

20leunam, 2025-05-12:
**Contexto**
Tenemos 2 demos, proponemos añadir alguna mas.

**Objetivo**
Añadir una nueva demo de Time trial pequeña y controlada.

**Propuesta**
Hardcodear movimientos para hacer un Time Trial de 3x3? 4x4? a una velocidad considerable(?)
Que arranque y vuelva a donde empezo para poder mostrar como se mueve el robot tambien.
Es valorable meter movimientos de 45º tambien para mas chorreo.

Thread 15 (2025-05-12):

Investigación de nuevas curvas clotoidianas de Keri-kun

robotaleh, 2025-05-12:
### Contexto
Para mejorar aún más la gestión de las curvas de Zoro es conveniente implementar nuevos perfiles de giro más complejos que abarquen más celdas como se puede ver en el [blog ](https://www.kerislab.jp/posts/2020-04-25-slalom-trajectory-3/)de Keri-kun

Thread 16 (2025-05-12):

Ajustar la llegada a la meta a la casilla de la meta mas lejana

20leunam, 2025-05-12:
**Contexto**
Cuando el robot llega a la meta (En las diagonales?) frena en la primera casilla de meta

**Objetivo**
Que el robot abance hasta la siguiente casilla para que frene un poco mas tarde ganando algunos ms

**Propuesta**
Añadir una casilla mas a la diagonal(?)

DjSteker, 2025-06-04:
me parece que no es correcto poner ningún Delay , mejor utilizar trenes de tareas

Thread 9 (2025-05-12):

Bajar succion en mapeo

20leunam, 2025-05-12:
**Contexto**
Durante el mapeo la succion va al 50%. Bajar al 30%(?)

**Objetivo**
Alargar la duracion de la lipo en laberintos grandes

robotaleh, 2025-05-16:
Aplicado en commit ea0c882ab7d2b7a5cab0000443a4369839549f6a

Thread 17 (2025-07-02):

Corregir el bug de la busqueda de nuevas rutas saliendo por una pared diferente de la que entro a la meta

20leunam, 2025-07-02:
**Contexto**
En el laberinto:
- - -
[PERSONALIZADOR DE LABERINTOS](https://oprobots.github.io/utils/maze-wall-placer.html)
[14,30,12,20,6,30,24,20,16,4,16,6,28,6,12,16,22,10,12,0,0,20,22,10,10,26,8,22,12,2,24,20,16,20,16,18,0,0,0,0,0,0,0,0,0,0,0,0,0,0,0,0,0,0,0,0,0,0,0,0,0,0,0,0,0,0,0,0,0,0,0,0,0,0,0,0,0,0,0,0,0,0,0,0,0,0,0,0,0,0,0,0,0,0,0,0,0,0,0,0,0,0,0,0,0,0,0,0,0,0,0,0,0,0,0,0,0,0,0,0,0,0,0,0,0,0,0,0,0,0,0,0,0,0,0,0,0,0,0,0,0,0,0,0,0,0,0,0,0,0,0,0,0,0,0,0,0,0,0,0,0,0,0,0,0,0,0,0,0,0,0,0,0,0,0,0,0,0,0,0,0,0,0,0,0,0,0,0,0,0,0,0,0,0,0,0,0,0,0,0,0,0,0,0,0,0,0,0,0,0,0,0,0,0,0,0,0,0,0,0,0,0,0,0,0,0,0,0,0,0,0,0,0,0,0,0,0,0,0,0,0,0,0,0,0,0,0,0,0,0,0,0,0,0,0,0]
- - -
Se da un problema en el mapeo. Llegando correctamente a la meta por un camino que no es la mas rapida, pero a la hora de buscar el camino más rapido tiene que salir por una pared diferente de la meta. Al intentarlo da una vuelta en la meta y se para contra la pared sin salir de la meta.

**Objetivo**
Corregir el error para que pueda salir por casillas "no mapeadas" de la meta

**Propuesta**
Que mapee todas las casillas establecidas como meta en el codigo si o si(?) añadiendo como objetivo inicial solo una casilla de las 4 y modificandolo una vez las alcance. Y asi poder posicionarse para salir por la casilla necesaria(?)

**Propuesta 2**
que salga por donde entro. y vaya a la casilla objetivo sin pasar por las casillas de meta(?)

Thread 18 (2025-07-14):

Resolver bug del mapeo donde si la ultima casilla interesante esta cerca de la salida se deja casillas sin visitar.

20leunam, 2025-07-14:
**Contexto**
Cuando el robot llego a la meta sigue buscando un camino mas optimo. Este camino lo va seteando segun avanza en funcion de las nuevas casillas exploradas. Pero siempre intentando llegar a la salida. Por tanto si llega un momento que visito nuevas casillas y tiene via libre a la salida, se va directamente a la salida pudiendo dejar casillas sin vistar del camino de resolucion final.

**Objetivo**
Conseguir que el robot mapee correctamente todas las casillas de la solucion en cualquier caso.

**Propuesta**
Que el calculo de las casillas interesantes las haga simulando siempre que esta en la meta, no desde donde esta.

Closed 2025-07-25.

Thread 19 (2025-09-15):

Fallo en el mosfet de succion en Zoro - C

20leunam, 2025-09-15:
Contexto
Cuando el robot se enciende el ventilador de succion se pone al 100% sin control

Objetivo
Cambiar el mosfet para volver a tener control sobre el ventilador

Propuesta
Cambiar el mosfet

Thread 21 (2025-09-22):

Mejora de control de velocidad lineal / angular mediante feedforward

20leunam, 2025-09-22:
**Contexto**
Nos han comentado un nuevo sistema para el control de la velocidad lineal del PID llamando feedforward

**Objetivo**
Intentar mejorar la precision en la velocidad lineal. con un control de PID basado en la caracterizacion del motor

**Propuesta**
Caracterizar el motor para tener una grafica Voltaje (o PWM) vs m/s para asi hacer que el robot siga un perfil de velocidad y sobre esa velocidad ejecutar un... PD? Para afinar la precision y variaciones posibles.

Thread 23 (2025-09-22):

Poder reusar un mapeo parcial para continuar mapeando en otros intentos.

20leunam, 2025-09-22:
**Contexto**
Si el robot no hace el mapeo completo. Solo guarda al llegar a la meta un mapeo parcial. Pero si quieres volver a intentar mapear hay que empezar de 0

**Objetivo**
Que el robot pueda mapear usando un mapeo parcial para no tener que repetir todo el mapeo de 0

**Propuesta**
Que el robot pueda mapear usando un mapeo parcial para no tener que repetir todo el mapeo de 0

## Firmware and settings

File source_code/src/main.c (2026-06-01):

#include <battery.h>
#include <buttons.h>
#include <control.h>
#include <delay.h>
#include <dragrace.h>
#include <encoders.h>
#include <floodfill.h>
#include <handwall.h>
#include <leds.h>
#include <lsm6dsr.h>
#include <macroarray.h>
#include <menu.h>
#include <motors.h>
#include <move.h>
#include <timetrial.h>

// #include <mpu6500.h>
#include <rc5.h>
#include <sensors.h>
#include <setup.h>
#include <usart.h>

void sys_tick_handler(void) {
  static uint8_t tick_count = 0;

  sm_emitter_adc();

  switch (tick_count) {
    case 0:
      clock_tick();
      break;
    case 1:
      check_leds_while();
      break;
    case 2:
      check_buttons();
      break;
    case 3:
      update_battery_voltage();
      break;
    case 4:
      update_encoder_readings();
      break;
    case 5:
      update_sensors_magics();
      break;
    case 6:
      lsm6dsr_update();
      break;
    case 7:
      control_loop();
      break;
    default:
      break;
  }

  tick_count = (tick_count + 1) % 16;
}

int main(void) {
  setup();
  eeprom_load();
  handle_robot_version();
  show_battery_level();

  printf("BA: %4d CI: %4d CD: %4d BO: %4d\n", get_aux_raw(AUX_BATTERY_ID), get_aux_raw(AUX_CURRENT_LEFT_ID), get_aux_raw(AUX_CURRENT_RIGHT_ID), get_aux_raw(AUX_MENU_BTN_ID));
  // floodfill_maze_print();
  while (1) {
    if (!is_race_started()) {
      menu_handler();
      if (!get_sensors_enabled() && menu_run_can_start()) {
        set_sensors_enabled(menu_run_can_start());
        delay(200);
      } else {
        set_sensors_enabled(menu_run_can_start() || is_debug_enabled());
      }
      if (menu_run_can_start()) {
        int8_t sensor_started = -1;
        if (menu_run_get_explore_algorithm() != EXPLORE_DRAGRACE) {
          sensor_started = check_start_run();
        }
        if (is_race_started()) {
          switch (menu_run_get_explore_algorithm()) {
            case EXPLORE_HANDWALL:
              switch (sensor_started) {
                case SENSOR_FRONT_LEFT_WALL_ID:
                  handwall_use_left_hand();
                  handwall_start();
                  break;
                case SENSOR_FRONT_RIGHT_WALL_ID:
                  handwall_use_right_hand();
                  handwall_start();
                  break;
              }
              break;
            case EXPLORE_FLOODFILL:
              switch (sensor_started) {
                case SENSOR_FRONT_LEFT_WALL_ID:
                  floodfill_start_run();
                  break;
                case SENSOR_FRONT_RIGHT_WALL_ID:
                  floodfill_start_explore();
                  break;
              }

              // configure_explore_kinematics(false);
              // configure_kinematics(SPEED_EXPLORE);

              // clear_info_leds();
              // set_RGB_color(0, 0, 0);
              // delay(125);
              // side_sensors_calibration(true);
              // delay(125);
              // if (is_battery_2s()) {
              //   set_target_fan_speed(get_kinematics().fan_speed_2s, 400);
              // } else {
              //   set_target_fan_speed(get_kinematics().fan_speed_3s, 400);
              // }
              // delay(800);

              // move(MOVE_START);
              // move(MOVE_BACK_STOP);

              // delay(1000);
              // set_race_started(false);

              break;
            case EXPLORE_TIME_TRIAL:
              timetrial_start();
              break;
            case EXPLORE_DRAGRACE:
              dragrace_start();
              break;
            default:
              set_race_started(false);
              break;
          }
        }
      }
    } else {
      switch (menu_run_get_explore_algorithm()) {
        case EXPLORE_HANDWALL:
          handwall_loop();
          break;
        case EXPLORE_FLOODFILL:
          floodfill_loop();
          break;
        case EXPLORE_TIME_TRIAL:
          timetrial_loop();
          break;
        default:
          set_race_started(false);
          break;
      }
    }
  }

  // ZONA DEBUG TEMPORAL

  while (1) {
    // LED WARNING
    // warning_status_led(125);

    // LEDS MENU
    // set_leds_wave(125);

    // LED RGB
    // set_RGB_color(20, 0, 0);
    // delay(250);
    // set_RGB_color(0, 20, 0);
    // delay(250);
    // set_RGB_color(0, 0, 20);
    // delay(250);
    // set_RGB_color(LEDS_MAX_PWM, LEDS_MAX_PWM, LEDS_MAX_PWM);
    // set_RGB_rainbow();

    // MPU
    // printf("MPU: 0x%02X\t", lsm6dsr_who_am_i());
    // printf("Z(raw): %6d Z(radps): %6.4f Z(dps): %6.4f Z(deg): %6.4f\t", lsm6dsr_get_gyro_z_raw(), lsm6dsr_get_gyro_z_radps(), lsm6dsr_get_gyro_z_dps(), lsm6dsr_get_gyro_z_degrees());
    // printf("Z(raw): %6d\t", lsm6dsr_get_gyro_z_raw());
    // delay(500);

    // VENTILADOR
    //  set_fan_speed(50);

    // MOTORES
    // gpio_set(GPIOB, GPIO15);
    // set_motors_speed(20, 20);

    // SENSORES
    // printf("S1: %4d S2: %4d S3: %4d S4: %4d\t", get_sensor_raw(SENSOR_FRONT_LEFT_WALL_ID, true), get_sensor_raw(SENSOR_FRONT_RIGHT_WALL_ID, true), get_sensor_raw(SENSOR_SIDE_LEFT_WALL_ID, true), get_sensor_raw(SENSOR_SIDE_RIGHT_WALL_ID, true));

    // AUX ANALÓGICOS
    // printf("BA: %4d CI: %4d CD: %4d BO: %4d\t", get_aux_raw(AUX_BATTERY_ID), get_aux_raw(AUX_CURRENT_LEFT_ID), get_aux_raw(AUX_CURRENT_RIGHT_ID), get_aux_raw(AUX_MENU_BTN_ID));
    // printf("BA: %.2f\n", get_battery_voltage());

    // ENCODERS
    // printf("L: %ld R: %ld\t", get_encoder_left_millimeters(), get_encoder_right_millimeters());

    // printf("\n");
    // delay(50);
  }

  return 0;
}

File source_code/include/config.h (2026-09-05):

#ifndef __CONFIG_H
#define __CONFIG_H

#include <stdint.h>
#include <stdio.h>

#ifndef MMSIM_ENABLED
#include "buttons.h"
#include "leds.h"
#include "sensors.h"
#endif

#define STM32_UID_BASE (0x1FFF7A10U)
#define UID_WORD0 MMIO32(STM32_UID_BASE + 0x0)
#define UID_WORD1 MMIO32(STM32_UID_BASE + 0x4)
#define UID_WORD2 MMIO32(STM32_UID_BASE + 0x8)

enum ROBOT_VERSION {
  ZOROBOT3_UNKNOWN = 0,
  ZOROBOT3_A = 1,
  ZOROBOT3_B = 2,
  ZOROBOT3_C = 3
};

/** Laberinto */
#define CELL_DIMENSION 180
#define CELL_DIAGONAL 127.3
#define WALL_WIDTH 12
#define MIDDLE_MAZE_DISTANCE ((CELL_DIMENSION - WALL_WIDTH) / 2.)
#define RIGHT_WALL_LOSS_TO_SENSING_POINT_DISTANCE 116
#define LEFT_WALL_LOSS_TO_SENSING_POINT_DISTANCE 110

/** Características Físicas */
#define MICROMETERS_PER_TICK 10.494055
#define ROBOT_FRONT_LENGTH 48.121
#define ROBOT_BACK_LENGTH 40.706
#define ROBOT_WIDTH 70.2
#define WHEELS_SEPARATION 62
#define ROBOT_MIDDLE_WIDTH ((ROBOT_WIDTH / 2.0))

/** Movimiento */
#define MAX_MOTOR_SATURATION_COUNT 100
#define MAX_MOTOR_ANGULAR_SATURATION_COUNT 60

/** Sensores */
#define SENSOR_LOW_PASS_FILTER_ALPHA 0.1

#define SENSOR_FRONT_CALIBRATION_READINGS 20
#define SENSOR_SIDE_CALIBRATION_READINGS 100
#define SENSOR_FRONT_DETECTION ((CELL_DIMENSION * 1.22))
#define SENSOR_SIDE_DETECTION 115 //((CELL_DIMENSION * 0.7))
#define SENSOR_RAW_THRESHOLD_DISTANCE_FACTOR 1.5f
#define SENSOR_DIAGONAL_REFERENCE_DISTANCE 320

#define USE_RAW_SENSORS true
// #define USE_DISTANCE_SENSORS true

/** Control de inicio de competición */
#define SENSOR_FRONT_DETECTION_START 100
#define SENSOR_START_MIN_MS 350

/** Divisor de Voltage */
#define VOLT_DIV_FACTOR_3S 5.30
#define VOLT_DIV_FACTOR_2S 3.15
#define BATTERY_2S_HIGH_LIMIT_VOLTAGE 8.4
#define BATTERY_2S_LOW_LIMIT_VOLTAGE 7.4
#define BATTERY_3S_HIGH_LIMIT_VOLTAGE 12.6
#define BATTERY_3S_LOW_LIMIT_VOLTAGE 11.0

/** Modo RUN */
#define CONFIG_RUN_RACE 1
#define CONFIG_RUN_DEBUG 0

void handle_robot_version(void);
void set_all_configs(void);
uint16_t get_config_run(void);

#endif

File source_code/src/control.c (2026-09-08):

#include "control.h"

static volatile bool race_started = false;
static volatile bool race_auto_run = false;
static volatile uint32_t race_finish_ms = 0;
static volatile uint32_t sensor_front_left_start_ms = 0;
static volatile uint32_t sensor_front_right_start_ms = 0;

static volatile bool control_debug = false;

static volatile int32_t target_linear_speed = 0;
static volatile int32_t ideal_linear_speed = 0;
static volatile float ideal_angular_speed = 0.0;

static volatile int32_t target_fan_speed = 0;
static volatile float ideal_fan_speed = 0;
static volatile float fan_speed_accel = 0;

static volatile int16_t ideal_front_distance = 0;

static volatile bool linear_error_correction_enabled = true;

static volatile float linear_error;
static volatile float sum_linear_error;
static volatile float last_linear_error;

static volatile bool angular_error_correction_enabled = true;

static volatile float angular_error;
static volatile float sum_angular_error;
static volatile float last_angular_error;

static volatile bool side_sensors_correction_enabled = false;
static volatile bool front_sensors_angle_correction_enabled = false;
static volatile bool front_sensors_distance_correction_enabled = false;
static volatile bool front_sensors_diagonal_correction_enabled = false;

static volatile float side_sensors_error;
static volatile float last_side_sensors_error;
static volatile float sum_side_sensors_error;

static volatile float front_sensors_angle_error;
static volatile float last_front_sensors_angle_error;
static volatile float sum_front_sensors_angle_error;

static volatile float front_sensors_distance_error;
static volatile float last_front_sensors_distance_error;
static volatile float sum_front_sensors_distance_error;

static volatile float front_sensors_diagonal_error;
static volatile float last_front_sensors_diagonal_error;
static volatile float sum_front_sensors_diagonal_error;

static volatile float voltage_left;
static volatile float voltage_right;
static volatile int32_t pwm_left;
static volatile int32_t pwm_right;

/**
 * @brief Convierte un valor de voltaje dado a su correspondiente PWM
 *
 * @param voltage
 * @return int32_t PWM a aplicar al motor
 */
#ifndef MMSIM_ENABLED
static int32_t voltage_to_motor_pwm(float voltage) {
  return voltage / /* 8.0  */ get_battery_voltage() * MOTORES_MAX_PWM;
}
#endif

#ifndef MMSIM_ENABLED
static int32_t normalize_fan_percentage(float percentage) {
  return percentage > 0 ? (int32_t)constrain(get_battery_high_limit_voltage() * percentage / get_battery_voltage(), percentage, 100.0f) : 0;
}
#endif

/**
 * @brief Actualiza la velocidad lineal ideal en función de la velocidad lineal objetivo y la aceleración
 *
 */
#ifndef MMSIM_ENABLED
static void update_ideal_linear_speed(void) {
  if (ideal_linear_speed < target_linear_speed) {
    int16_t accel = get_kinematics().linear_accel.accel_soft;
    if (get_kinematics().linear_accel.speed_hard == 0 || ideal_linear_speed < get_kinematics().linear_accel.speed_hard) {
      accel = get_kinematics().linear_accel.accel_hard;
    }
    ideal_linear_speed += accel / CONTROL_FREQUENCY_HZ;
    if (ideal_linear_speed > target_linear_speed) {
      ideal_linear_speed = target_linear_speed;
    }
  } else if (ideal_linear_speed > target_linear_speed) {
    ideal_linear_speed -= get_kinematics().linear_accel.break_accel / CONTROL_FREQUENCY_HZ;
    if (ideal_linear_speed < target_linear_speed) {
      ideal_linear_speed = target_linear_speed;
    }
  }
}

static void update_fan_speed(void) {
  if (ideal_fan_speed < target_fan_speed) {
    ideal_fan_speed += fan_speed_accel / CONTROL_FREQUENCY_HZ;
    if (ideal_fan_speed > target_fan_speed) {
      ideal_fan_speed = target_fan_speed;
    }
  } else if (ideal_fan_speed > target_fan_speed) {
    ideal_fan_speed += fan_speed_accel / CONTROL_FREQUENCY_HZ;
    if (ideal_fan_speed < target_fan_speed) {
      ideal_fan_speed = target_fan_speed;
    }
  }
}

static float get_measured_linear_speed(void) {
  return (get_encoder_left_speed() + get_encoder_right_speed()) / 2.0f;
}

static float get_measured_angular_speed(void) {
  return -lsm6dsr_get_gyro_z_radps();
}
#endif

/**
 * @brief Comprueba si el robot está en funcionamiento
 *
 * @return bool
 */

bool is_race_started(void) {
  return race_started;
}

/**
 * @brief Establece el estado actual del robot
 *
 * @param state Estado actual del robot
 */

void set_race_started(bool state) {
  race_started = state;

#ifndef MMSIM_ENABLED
  reset_control_all();
  set_sensors_enabled(state);
  if (!state) {
    menu_reset();
    race_finish_ms = get_clock_ticks();
    disable_sensors_correction();
  }
#endif
}

bool is_race_auto_run(void) {
  return race_auto_run;
}

void set_race_auto_run(bool state) {
  race_auto_run = state;
}

void set_control_debug(bool state) {
  control_debug = state;
}

#ifndef MMSIM_ENABLED
int8_t check_start_run(void) {
  if (get_sensor_distance(SENSOR_FRONT_LEFT_WALL_ID) <= SENSOR_FRONT_DETECTION_START) {
    if (sensor_front_left_start_ms == 0 && sensor_front_right_start_ms == 0) {
      sensor_front_left_start_ms = get_clock_ticks();
    }
  } else {
    sensor_front_left_start_ms = 0;
  }
  if (get_sensor_distance(SENSOR_FRONT_RIGHT_WALL_ID) <= SENSOR_FRONT_DETECTION_START) {
    if (sensor_front_left_start_ms == 0 && sensor_front_right_start_ms == 0) {
      sensor_front_right_start_ms = get_clock_ticks();
    }
  } else {
    sensor_front_right_start_ms = 0;
  }

  bool left_ready = sensor_front_left_start_ms > 0 && get_clock_ticks() - sensor_front_left_start_ms >= SENSOR_START_MIN_MS;
  bool right_ready = sensor_front_right_start_ms > 0 && get_clock_ticks() - sensor_front_right_start_ms >= SENSOR_START_MIN_MS;
  if (left_ready || right_ready) {
    uint8_t sensor = left_ready ? SENSOR_FRONT_LEFT_WALL_ID : SENSOR_FRONT_RIGHT_WALL_ID;
    sensor_front_left_start_ms = 0;
    sensor_front_right_start_ms = 0;
    set_RGB_color(0, 50, 0);

    set_race_auto_run(false);
    uint32_t starting_ms = get_clock_ticks();
    while (get_clock_ticks() - starting_ms < 2000) {
      warning_status_led(50);

      if (sensor == SENSOR_FRONT_RIGHT_WALL_ID) {
        if (get_sensor_distance(SENSOR_FRONT_LEFT_WALL_ID) <= SENSOR_FRONT_DETECTION_START) {
          if (sensor_front_left_start_ms == 0 && sensor_front_right_start_ms == 0) {
            sensor_front_left_start_ms = get_clock_ticks();
          }
        } else {
          sensor_front_left_start_ms = 0;
        }

        if (sensor_front_left_start_ms > 0 && get_clock_ticks() - sensor_front_left_start_ms >= SENSOR_START_MIN_MS) {
          set_RGB_color(50, 0, 50);
          set_race_auto_run(true);
        }
      }
    }
    set_RGB_color(0, 0, 0);
    set_status_led(false);

    set_race_started(true);
    menu_run_reset();
    return sensor;
  }
  return -1;
}
#endif

void set_linear_error_correction(bool enabled) {
  linear_error_correction_enabled = enabled;
}
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

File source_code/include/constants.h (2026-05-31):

#ifndef __CONSTANTS_H
#define __CONSTANTS_H

/** Laberinto (dimensiones máximas)*/
#define MAZE_ROWS 16
#define MAZE_COLUMNS 16
#define MAZE_CELLS (MAZE_ROWS * MAZE_COLUMNS)
#define MAZE_MAX_DISTANCE (MAZE_CELLS - 1)

/** Constantes matemáticas */
#define PI 3.1415
#define MICROMETERS_PER_MILLIMETER 1000
#define MILLIMETERS_PER_METER 1000
#define MICROSECONDS_PER_SECOND 1000000

/** Constantes del STM32F4 */
#define SYSCLK_FREQUENCY_HZ 168000000
#define SYSTICK_FREQUENCY_HZ 16000
#define UPDATE_FREQUENCY_HZ 1000
#define CONTROL_FREQUENCY_HZ 1000
#define LEDS_MAX_PWM 1024
#define MOTORES_MAX_PWM 1024
#define MOTORES_SATURATION_PWM 1000
#define MOTORES_SATURATION_ANGULAR_SPEED 50
#define ADC_RESOLUTION 4096
#define ADC_LSB (3.3 / ADC_RESOLUTION)

#endif

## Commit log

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2020-01-29 Ordena correctamente los RGB
    [leds.c, main.c]
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2022-10-31 Corrige lectura de nivel de batería
    [config.h, setup.c]
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2022-10-31 Corrige el pin de lecutra del módulo de arranque
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2023-04-30 Añade ficheros de modelo 3D, STLs y programa básico y actualiza README
    [Encoders_Fuji.sch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]
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2023-09-30 Actualiza el codigo para que funcione como Zoro2.9 Se establece como punto de partida para afinarlo.
2023-10-04 Añade Kw y usa Ki Consigue que el robot complete aunque tiene algunos esfrunfeles
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2023-10-06 Añade freno con deteccion pared de alante y duplica la velocidad para que no se choque contra las paredes
2024-03-08 Corrige MPU a 168mhz y añade demo estática
    [main.c, mpu.c, setup.c]
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2024-03-29 Corrige warnings de compilación
    [debug.c, leds.c]
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2024-03-29 Refactor y ajustes de funciones en encoders para usar mm cuando sea posible
2024-03-29 Añade actualización de batería en systick y mejora calibración de divisor resistivo
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2024-03-31 Añade funciones de movimiento lineal y rotación inplace usando encoders y gyro
2024-04-02 Añade log escalable por macroarrays e inicio por detección de led frontal
2024-04-02 Añade offset de dimensiones de robot al cálculo de distancias de los sensores
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2024-04-17 Corrige distancia de inicio manual por sensor
    [main.c]
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2024-04-19 Vuelve a 84MHz 😢 y configura el PWM de los motores a 20kHz
2024-04-19 Corrige las restricciones de PWM para evitar sobrepasar el máximo
    [motors.c]
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2024-04-19 Añade cálculo y gestión de error frontal y detección de paredes
    [config.h, control.c, main.c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]
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2024-04-29 Mejora el algoritmo de handwall · Añade define de SENSING_POINT_DISTANCE · Corrige ROBOT_BACK_LENGTH · Reemplaza distancias del algoritmo por sus defines · Añade move_straight_until_front_distance · 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
    [config.h, main.c, move.c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]
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2024-04-30 Añade reseteo de errores al reactivar control de sensores y obtención de velocidad lineal ideal
    [control.c]
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2024-04-30 Ajusta la función move_straight para tener en cuenta el espacio de frenado al detenerse
2024-04-30 Corrige movimiento inicial al Sensing Point y añade aviso del led al alcanzarlo
    [main.c]
2024-04-30 Mejora la secuencia de inicio y la gestión del tiempo máximo de ejecución
2024-05-01 Modifica el menú para Calibraciones y Debug y lo añade al main
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2024-05-03 Añade control de desplazamientos relativo a la celda actual, giro en el sitio con aceleraciones y mejoras varias · Funciones para resetear el control y deshabilitar la corrección de sensores · Frenad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
    [control.c, encoders.c, motors.c]
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2024-05-06 Mejora la calibración de sensores, la gestión de movimientos y corrige pines del RGB
    [config.h, leds.c, main.c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]
2024-05-14 Mejora en general la fiabilidad y control · Giros en 180 con aceleraciones · Calibración de constantes de giros · Calibración de constantes de sensores · Filtros de paso bajo en lectura de velocidad 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
    [config.h, control.c, debug.c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]
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2024-05-26 Añade control de perdida de pared para reseteo de posición en casilla y ajusta la distancia de entrada de los giros
    [control.c, main.c, move.c]
2024-05-27 Añade cambios mágicos que parecen hacer que funcione Resetea angular_error cuando ambas correcciones de pared lateral se desactivan
    [control.c, main.c, move.c]
2024-05-29 Mejora reseteo de error angular
    [control.c, move.c]
2024-05-31 Mejora calibración de sensores frontales y ajusta el cálculo general de distancias
2024-06-05 Elimina proyecto antiguo de PCB
    [Encoders_Fuji.sch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]
2024-06-05 Configura el proyecto de kicad de la rebuild de la nueva PCB
    [ZoroBot3.kicad_pcb, ZoroBot3.kicad_sch]
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2024-06-24 Añade corrección angular y longitudinal con sensores frontales en giros de 180º
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2024-06-26 Añade guardado de laberinto en EEPROM y función de debug para añadir paredes
2024-06-26 Comenta reseteo de casilla por "pérdida de poste"
    [move.c]
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2024-07-10 Renombra menú actual a menu_configs y corrige includes
    [eeprom.h, main.c]
2024-07-11 Añade nuevo menú optimizado para la rebuild y refactoriza el código ligeramente el código de floodfill
2024-07-11 Añade calculo de camino más corto hasta la meta y refactor general de floodfill.c
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2024-07-12 Corrige generación de secuencia de carrera
2024-07-12 Añade corrección lateral y longitudinal de giros usando sensores Esta corrección es especialmente útil en consecuciones de giros sin reseteos
    [move.c]
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2024-07-16 Añade reseteo de casillas en resolución
    [move.c]
2024-07-17 Corrige la prioridad del TIM2 para solucionar problema de ruido en la lectura de sensores
    [setup.c]
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2024-07-19 Añade funciones para cálculo de error en diagonales
    [config.h, control.c, sensors.c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]
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2024-07-23 Implementa ajustes importantes en menú y gestión de runs · Desactiva el reseteo de casillas en resolución (es necesario mejorarlo para resetear solo cuando sea necesario) · Añade suavizado de secuenc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
    [move.c]
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2024-07-25 Corrige calibración de sensores frontales
    [sensors.c]
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2024-07-25 Añade opción para cambiar de MODE_HOME a MODE_COMPETITION desde el menú, cambiando dimensiones y meta del laberinto
2024-07-25 Activa de nuevo las correcciones de pared frontal y lateral en mapeo
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2024-07-26 Añade código funcional para diagonales Nota: los perfiles de velocidad están modificados para pruebas
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2024-08-17 Corrige generación de path de diagonales
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2024-08-20 Corrige suavizado de ruta de resolución
2024-08-20 Corrige la asignación de velocidad de succión a 0-100
    [motors.c]
2024-08-20 Corrige calibración de sensores frontales para sobreescribir su offset
    [sensors.c]
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2024-08-22 Elimina integrales de los errores frontal y angular
    [control.c]
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2024-08-23 Mejora nomenclatura de funciones de reseteo de sensores y aplica los cambios propuestos en #1
    [config.h, control.c, motors.c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]
2024-08-28 Añade pausa al llegar a la meta en mapeo para guardar el floodfill en EEPROM Evita la pérdida del mapeo en los casos en los que el robot se choque o se pierda volviendo de la meta a la casilla de sal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
2024-08-28 Mejora gestión de diagonales · Desactiva corrección de sensores en la entrada · Desactiva offsets de inicio y fin para los giros de diagonales · Comenta la desactivación de correción diagonal en las 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
2024-08-29 Añade una quinta configuración de velocidad y ajusta los perfiles de velocidades y giros
2024-08-29 Establece la velocidad de explore y run en función de la configuración seleccionada
2024-08-29 Mejora el menú de arranque para no depender de un led de configuración
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2024-09-03 Corrige deceleración de velocidad de ventilador
    [control.c]
2024-10-08 Añade parada para guardar el laberinto en EEPROM al llegar a la meta
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2024-12-16 Comienza a plantear el esquematico de la rebuild
    [Encoders.kicad_sch, MPU.kicad_sch, ZoroBot3.kicad_sch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]
2024-12-26 Añade nuevo MPU LSM6DSR
    [MPU.kicad_sch, ZoroBot3.kicad_sch]
2024-12-29 Añade receptor IR SMD TSSP77038TR
    [ZoroBot3.kicad_sch]
2024-12-31 Finaliza (En principio) el esquematico
    [Encoders.kicad_sch, MPU.kicad_sch, ZoroBot3.kicad_sch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]
2024-12-31 Correlaciona toda la NetList, añade EdgeCuts y comienza el posicionamiento de componentes
    [Encoders.kicad_sch, MPU.kicad_sch, ZoroBot3.kicad_pcb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]
2025-01-01 Corrige errores de esquematico, crea las PCBs auxiliares, y posiciona todos los elementos para comenzar el ruteado.
    [Encoders.kicad_sch, MPU.kicad_sch, ZoroBot3.kicad_pcb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]
2025-01-05 Finaliza el diseño de la PCB de ZoroBot3 Rebuild y añade gerbers y BOM
    [Encoders.kicad_sch, MPU.kicad_sch, ZoroBot3.kicad_pcb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]
2025-01-06 Cambia el puente H al MP6551
    [ZoroBot3.kicad_pcb, ZoroBot3.kicad_sch]
2025-01-06 Desplaza ventilador y leds 2mm hacia adelante para hacer hueco a la bateria
    [ZoroBot3.kicad_pcb, bom.csv, designators.csv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]
2025-01-26 Actualiza pinout y setup de periféricos y añade test para el nuevo hardware
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2025-03-10 Realiza preparativos de la adecuacion del hardware y comentarios en el esquematico
    [ZoroBot3.kicad_sch, sensores.kicad_sch]
2025-03-10 Corrige índice de analógicos auxiliares
    [sensors.h]
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2025-03-10 Corrige dirección del motor izquierdo
    [motors.c]
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2025-03-12 Corrige interrupción RC5 y deshabilita sensores por defecto
    [main.c, sensors.c, sensors.h]
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2025-03-15 Corrige los leds indicativos de calibración de sensores frontales
    [leds.c]
2025-03-15 Pasa la calibración del MPU a decimal para mejorar precisión y añade guardado en EEPROM
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2025-03-18 Corrige el indicador de batería completamente cargada
    [leds.c]
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2025-03-26 Actualiza las magias de los sensores para usar ecuaciones logaritmicas y simplifica los cálculos
2025-03-28 Corrige (aparentemente) el fallo de los canales mezclados del ADC · Es necesario configurar primero el DMA y, posteriormente, el ADC
    [setup.c]
2025-03-28 Añade botón debug virtual (desde IRStart) para acciones sin tocar el robot
2025-03-28 Ajusta los micrómetros por tick de los encoders y elimina filtro de paso bajo del cálculo de la velocidad
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2025-04-05 Corrige debug de corriente de motores
    [debug.c]
2025-04-05 Comenta el guardado de eeprom al iniciar carrera Ahora se guarda al activar el RGB en Morado
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2025-04-05 corrige movimiento de retroceso para que se detenga al final
    [move.c]
2025-04-05 Actualiza distancia de reseteo de pérdida de pared
    [move.c]
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2025-04-21 Corrige gambada de vel 0 al saturar motores
    [motors.c]
2025-04-23 Corrige movimiento de media vuelta para comprobar si existe pared frontal
    [config.h, control.c, move.c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]
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2025-04-25 Corrige el switch de velocidades al obtener la run sequence
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2025-04-26 Corrige la distancia final de los giros de 180
    [move.c]
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2025-04-26 Corrige orden de los parámetros de los macroarrays
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2025-04-30 Añade cálculo de errores de pared estilo Peter Harrison
    [config.h, control.c, sensors.c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]
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2025-05-01 Deshabilita la corrección diagonal a una casilla del final para evitar falsos errores con las paredes frontales
    [move.c]
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2025-05-02 Añade reseteo de distancia recorrida
    [control.c, encoders.c]
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2025-05-02 Corrige macroarrays para evitar shifteo de posiciones al desbordar
2025-05-02 Corrige control de pérdida de pared en run_straight (línea eliminada por error)
    [move.c]
2025-05-02 Corrige gestión de offsets rectos de giros en run
    [move.c]
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2025-05-02 Ajusta la desactivación de error diagonal a media casilla del final
    [move.c]
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2025-05-05 Corrige cálculo de frenada antes de curvas
    [move.c]
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2025-05-09 Corrige fallo de offset inicial de movimiento recto
    [control.c, move.c]
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2025-05-14 Actualiza STLs de Zoro3 rebuild
    [Part Studio - Arandela M2 -editada-.stl, Part Studio - Arandela M3 -editada-.stl, Part Studio - Bracket Motor L.stl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]
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2025-06-02 Corrige signo de velocidad angular de encoders
    [encoders.c]
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2025-07-14 Corrige el bug de la busqueda de nuevas rutas saliendo por una pared diferente de la que entro a la meta #17
2025-07-25 Mejora la exploración del laberinto para buscar todas las posibles rutas fix #18
    [sensors.h]
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2025-09-01 Corrige el movimiento BACK sin pared frontal y habilita cálculo de distancia frontal con los dos sensores frontales
    [move.c]
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2025-09-04 Aceleraciones en zonas conocidas del mapeo Fixes #8
    [menu_run.h]
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2025-09-16 Corrige guardado de EEPROM de calibración de MPU
    [lsm6dsr.c]
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2025-09-30 Girar en las rectas solo cuando se haya detectado perdida de pared. Fixes #20
    [control.c, move.c]
2026-02-16 Corrige los demos de MPU y Succión
    [control.c, debug.c]
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2026-02-27 Corrige error de creación de run_sequence e inicio de run/mapeo
2026-02-28 Corrige logica de reseteo por pérdida de pared y espera a pérdida de pared antes de giro en run (CREO)
    [control.c, move.c]
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2026-02-28 Corrige bucle infinito al volver a casilla de salida en mapeo
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2026-03-03 Mejora corrección de sensores en MOVE_HOME y elimina funciones deprecated de close y far side errors closes #28
    [control.c, move.c, sensors.c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]
2026-03-03 Corrige finalización de race al terminar explore
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2026-03-03 Añadir un Time Trial chiquito a las demos Fixes #14
    [debug.c]
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2026-03-03 Asignar PWM de ventilador de succión en función de la batería Fixes #4
    [control.c]
2026-03-03 Corrige constantes de PID de corrección diagonal
    [move.c]
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2026-03-04 Corrige velocidad final antes de MOVE_HOME
    [move.c]
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2026-03-04 Corrige gambada de cambio de signo en aca7d8c5
    [move.c]
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2026-03-04 Corrige bug de smooth_run_sequence al terminar en SALIDA
2026-03-06 Corrige run_sequence de vuelta a START después de RUN
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2026-03-07 Corrige enendido de LED_E
2026-03-07 Corrige error de offset en mapeo ocasionado por 430863465b258b306a1b5a75104aae145df8c400
    [move.c]
2026-03-07 Corrige bug en last_cell_wall_lost cuando la última casilla no tiene pared en la dirección de giro #26
    [move.c]
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2026-03-09 Corrige bug de aproximación a pared frontal despues de giro. Fixes #30
    [move.c]
2026-03-12 Añade comando para EXPLORE_TYPE y corrige run_back_to_start
2026-03-12 Añade comando para EXPLORE_TYPE y corrige run_back_to_start (2)
2026-03-12 Corrige ruta final para sim_main.c
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2026-04-20 Corrige offsets de start y end en MOVE_45_TO_45
    [move.c]
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2026-04-24 Corrige inicio de run desde RC5
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2026-05-31 Actualiza SysTick a 16kHz y mueve todas las interrupciones ahí para sincronizarlas Fixes #39 #41
    [constants.h, encoders.c, lsm6dsr.c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]
2026-05-31 Añade reseteo de error lateral al re-habilitar corrección
    [control.c, sensors.c, sensors.h]
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2026-05-31 Corrige desbordamiento de cola y orden de inserción en floodfill
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2026-05-31 Resetea también los ticks totales en reset_encoders y renombra la función reset_encoder_avg
    [control.c, encoders.c]
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2026-06-23 Corrige (espero) añadido de múltiples `latest` en readthedocs
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2026-08-03 Actualiza esquemático para añadir SRAM, lectura de corriente y diodo en succión
    [Encoders.kicad_sch, MPU.kicad_sch, ZoroBot3.kicad_pcb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]
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2026-08-30 Finaliza la version V1.2 con SRAM y correccion de errores.
    [MPU.kicad_sch, ZoroBot3.kicad_pcb, ZoroBot3.kicad_sch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]
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2026-09-03 Corrige handwall_start para forzar SPEED_EXPLORE
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2026-09-03 Divide los parámetros de las correcciones para mejorar debug y ajusta reseteo de correcciones al rehabilitar la corrección
    [control.c]
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2026-09-06 Corrige final de mapeo en modo EXPLORE_COMPLETE
2026-09-06 Corrige error de condición en keep_front_distance
    [move.c]
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2026-09-08 Añade reseteo faltante a reset_control_errors
    [control.c]
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2026-09-08 Revert "Añade sistema de precaución con peines en floodfill_run"
    This reverts commit b27d7107dac5243cd4531994aa15f22dad8a2f9b.
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
